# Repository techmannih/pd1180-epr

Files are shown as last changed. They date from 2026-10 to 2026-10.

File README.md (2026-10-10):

# PD1180-EPR — NEMA 34 Smart Motor-Mounted Stepper Controller with USB-C PD 3.1 EPR

PD1180-EPR is an 85.9 × 85.9 mm, four-layer controller for the ordered STEPPERONLINE 34HS31-6004S1 NEMA 34 motor (Amazon ASIN B091C83HWF). Its rated holding torque is 4.8 Nm and rated current is 6 A/phase; the driver RMS/hold-current setting and driven load remain unqualified. J1 is the dedicated 48 V / 5 A USB Power Delivery 3.1 EPR input; J10 is a separate USB 2.0 device-data port. The board combines protected power entry, a TMC5160A external-MOSFET motor stage, STM32G0B1 control, magnetic position feedback and industrial control interfaces.

**Revision:** r0.4 reference ECO · **Status:** CAD routing verified; powered validation pending · **Assembly:** top only · **Order status:** HOLD

**Reference-board changes:** Retain the separate PD POWER / USB DATA ports, industrial J7 harness and TMC5160 external bridges. Add TMP102 hardware temperature inhibit, INA240 phase-current diagnostics, ADS1115 bus telemetry and a DATA-powered logic supply. Place bootstrap/gate/bypass parts locally and preserve Kelvin connections to the shunt terminals. Native routing, DRC, schematic parity, ERC and Kelvin isolation pass. Physical USB power validation remains open. The STM32 commissioning firmware is motion-locked. TI programming and powered tests are also pending.

[View the board on tscircuit](https://tscircuit.com/techmannih/NEMA-34-Smart-Motor-Mounted-Stepper-Controller) · [Open the manufacturing release](release/) · [Read the reviewer checklist](docs/reviewer-checklist.md)

The main 3D tab shows the routed PCB with the ordered motor and proposed adapter. The image below shows the bare PCB. The release archives are regenerated for engineering review. Ordering remains on hold; the commissioning firmware keeps motion locked pending TI programming and powered validation.

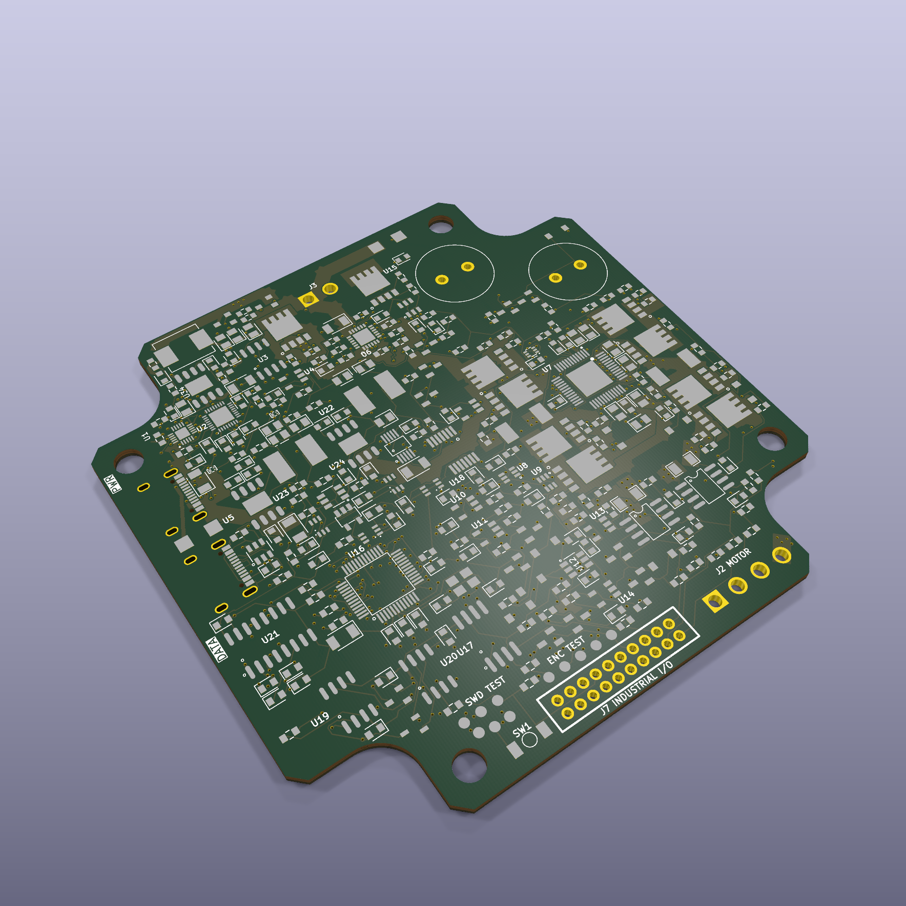
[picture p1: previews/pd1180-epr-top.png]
Routed r0.4 ECO PCB


## What must arrive with the assembled board

The intended purchase is **PCB fabrication plus complete assembly, programming and functional test**, so the delivered PCBA can operate with its specified motor, power source and harness. Bare-PCB electrical testing and soldering the components do not establish motor operation. Programming and powered testing must be explicitly included in the accepted assembly/test work order; they are not assumed to be included in an SMT assembly quote.

**The current release cannot yet deliver a ready-to-run motor controller.** No assembled hardware has been tested. U3's TI PD image is missing, and the supplied STM32 commissioning image deliberately blocks motor power and motion, including after `ARM`. The following deliverables are required before accepting a board as ready to run:

| Deliverable | Required handoff / present status |
|---|---|
| Complete populated PCBA | Matching Gerbers, BOM and CPL; 294 fitted parts on top, including an agreed through-hole/tall-part assembly plan. CAD verified; assembly not ordered. |
| U3 PD-controller EEPROM | Approved TI-generated TPS26750 full-flash binary, SHA-256 and programming/readback record. **Binary pending.** The requirements JSON is not flashable firmware. |
| U16 STM32 firmware | Board-specific, motor-enabled firmware with a recorded hash and validated motor/current settings. **Only motion-locked commissioning firmware is supplied today.** |
| Functional acceptance | Board serial number, firmware/configuration hashes and measured rail, PD, motor, fault and thermal results. **All powered results pending.** |
| External system | Confirmed motor, EPR source/cable, 24 V control source, mating harnesses, brake resistor/heatsink, magnet and mounting hardware; these are outside the populated-PCB BOM. |

First articles need staged engineering qualification using [the power-validation test matrix](docs/power-validation.md), followed by an agreed per-board acceptance test for the assembled batch. If the assembler does not provide programming or motor testing, arrange a separate commissioning provider before calling the delivery ready to run. The manufacturing request and pending programming fields are in [order-settings.json](release/order-settings.json); detailed acceptance requirements are in [assembly.md](docs/assembly.md).

The [provider request and first-article programming sequence](docs/assembly.md#request-to-send-to-the-assemblytest-provider) are ready for review. Provider acceptance and the [motor/load qualification inputs](docs/power-validation.md#qualification-work-sheet-for-the-provider) remain open. Programming and the accepted motor tests must finish before shipment.

## Connections and operation

The selected operating mode is **external STEP/DIR with USB setup and diagnostics**. The STM32 supervises power, configures the TMC5160A and checks faults. External pulses pass through the 24 V input circuitry to the TMC5160A, which drives the external MOSFET bridges and regulates the motor phase currents. USB DATA alone cannot power the motor. Industrial transceivers are fitted, but CANopen, serial motion commands and closed-loop positioning are not implemented in the current firmware.

Make motor/brake/harness connections with power removed and the bus discharged. Identify each motor winding from its verified pinout or a resistance measurement; wire colours are not a pinout.

| Connection | Wiring |
|---|---|
| J1 **PD POWER** | Source explicitly supporting a 48 V / 5 A EPR contract, with a suitable 5 A EPR cable. A USB-C connector alone does not establish this capability. |
| J10 **USB DATA** | USB data cable to the setup/diagnostics host. Its independent 5 V input supplies MCU logic, not VMOTOR. |
| J2 **MOTOR** | Pin 1 A1, pin 2 A2 (one winding); pin 3 B1, pin 4 B2 (the other winding). Never connect/disconnect the motor while powered. |
| J3 **BRAKE** | The selected resistor connects between pin 1 VMOTOR and pin 2 switched BRAKE_RETURN. Pin 2 is not a permanent ground. Fit the reviewed heatsink. |
| J7 **STEP/DIR** | Pin 6 STEP, pin 7 DIR, pin 18 hardware ENABLE; nominal 24 V inputs referenced to pin 8 GND. Use a compatible 24 V controller/level interface; do not treat these as direct 3.3 V GPIO inputs. |
| J7 **limits** | Pin 1 HOME, pin 2 STOP L, pin 3 STOP R. Qualify their polarity and stop response during commissioning. Full industrial pinout is below. |
| J7 pin 17 | Protected **VMOTOR, nominal 48 V**; not a 24 V control supply. Obtain the control-input 24 V supply separately. |

Use the physical pin-1 marker and numbered footprint, not the apparent left/right order of a photograph. The STEP/DIR transistor inputs invert their signals; validate step edge, direction setup/hold time and maximum pulse rate at the TMC5160A before configuring the external motion controller.

### First start with the supplied commissioning firmware

1. Complete the unpowered inspection in [bring-up.md](docs/bring-up.md). Keep J1 and the motor disconnected and hardware enable inactive for the initial J10 diagnostic check.
2. If U16 has not been programmed, use ST-LINK/SWD with SWDIO, SWCLK, NRST, GND and the board's 3.3 V reference. Program the verified `firmware.bin` from [the commissioning archive](release/pd1180-commissioning-firmware.zip) at `0x08000000`, verify and reset. Follow [firmware/README.md](firmware/README.md) for the exact MCU and power arrangement. This binary belongs in U16, not U3.
3. Connect J10 and open its USB CDC serial port. Send `HELP`, `STATUS`, `DRIVER` or `DISARM`, each followed by a newline. With J10 alone, `BOARD_OK=0` is expected because the PD-powered peripherals are off; `RUN=0` and `BRINGUP_REQUIRED=1` must remain set as shown.
4. `ARM` currently returns `BLOCKED: ECO hardware and TI configuration not verified`. This is expected, not a wiring workaround. Do not bypass the lock or bridge an enable signal to make the motor run.
5. Commission U3 and the J1 power path with the approved TI image and instrumented, staged tests before connecting a motor. Then qualify a motor-enabled STM32 release, initially below 1 A RMS and only increasing current after gate, current and thermal measurements pass. **This qualification has not happened yet.**

### Normal use after the motor-enabled release is qualified

Connect the confirmed motor, brake and industrial harness while unpowered, with STEP pulses stopped and hardware enable inactive. Connect J10 for diagnostics and J1 for motor power. Verify the approved PD contract, board/driver rails and fault status, select the qualified current/microstep settings, then explicitly arm and assert external enable. Apply a low-rate STEP train with DIR stable; increase speed and load only within the recorded operating envelope. Pulse frequency sets speed and DIR selects direction; the current setting is independent of pulse frequency.

To stop normally, decelerate the STEP train using the validated stop profile, remove enable and disarm before removing power. A fault, reset or power interruption must leave the bridge inhibited and require deliberate re-arming. Loss of torque is not a mechanical holding brake; a gravity-loaded axis needs its own holding arrangement. The final motor-enabled release must supply its exact command/settings procedure and measured operating limits; the commissioning image above cannot execute this normal-use sequence.

## Feature overview

| Area | Implementation |
|---|---|
| USB-C power | TPS26750 sink-only USB PD 3.1 EPR controller requesting 48 V / 5 A |
| USB ports | J1 PD POWER and J10 USB DATA; separate VBUS rails |
| USB protection | TPD4S480 on PD CC/SBU; USBLC6-4SC6 on DATA D+/D−/CC, independent 5.1 kΩ CC pulldowns and DATA VBUS sensing |
| Input protection | TPS26631 eFuse, inrush control, voltage qualification, current limit and reverse-current blocking |
| Motor stage | TMC5160A with eight 100 V CSD19534Q5A MOSFETs and two 33 mΩ phase shunts |
| Ordered motor | STEPPERONLINE 34HS31-6004S1, 4.8 Nm, 6 A/phase; approved driver current setting pending |
| Controller | STM32G0B1CBT6 with USB device, CAN, SPI, I²C and serial peripherals |
| Position feedback | Top-side AS5047P magnetic encoder at the shaft axis, with ABI test access |
| Temperature/current diagnostics | TMP102 hardware inhibit; two INA240 phase monitors; ADS1115 bus monitors |
| Motion inputs | 24 V Step/Dir plus HOME, left stop and right stop inputs |
| Communications | USB 2.0, CAN, RS485 and RS232 |
| Outputs | Hardware enable plus two protected low-side outputs |
| Braking | External switched brake-resistor interface with independent overvoltage shutdown |
| Programming | SWD for STM32 and configuration EEPROM for the PD controller |
| Assembly | 294 JLC-sourced fitted parts plus 11 service test pads, all on top |

The board powers up inhibited. A valid EPR contract, eFuse status, motor-power-good signal, voltage window, external hardware enable and MCU request must all agree before the bridge can run. Reset defaults keep `POWER_PERMIT`, `MCU_RUN`, `RS485_DE`, both protected outputs and standalone-mode selection inactive.

## Power architecture

```text
J1 PD POWER VBUS -> reverse blocking / eFuse -> VMOTOR -> bridge power / TMC5160 VS
        |                                       |       motor J2 / brake J3
        |                                       +-> U34 12 V -> TMC5160 VSA/12VOUT
        +-> U5 3.3 V startup supply              +-> U22 3.3 V brake-control backup
                         U23 / U24 reverse-blocked OR -> V3V3
J1 CC1/2 -> U1 protection -> U2 TPS26750 EPR controller
J10 USB DATA D+/D- -> D15 shunt ESD -> R71/R72 -> STM32 USB
J10 VBUS -> U28 current limiter -> U25 LDO -> V3V3_USB
board V3V3 / V3V3_USB -> U26 / U27 reverse-blocked OR -> V3V3_MCU
```

DATA alone powers MCU setup/diagnostics on V3V3_MCU. Industrial interfaces, flash, encoder and sensors remain on board V3V3 supplied by J1/VMOTOR. Open-drain chip selects and inactive peripheral pins prevent MCU-driven backfeed. Firmware now implements USB suspend with STOP0, watchdog wake and fresh power/sensor qualification after resume; measured current, inrush, wake timing and source handovers remain unverified. U22 retains VMOTOR-fed brake control. The commissioning image keeps the motor locked.

The requested contract is 240 W. The nominal eFuse current limit is approximately 4.48 A, so the board-side motor input limit is about 215 W at 48 V before conversion and switching losses. USB input current and phase current are different quantities; the motor-stage target is 5.5 A RMS per phase.

The 940 µF motor bulk bank stores only about 0.188 J between 48 V and the revised nominal 51.99 V brake turn-on threshold. It cannot absorb sustained regeneration. J3 connects a separately selected braking resistor and heatsink; 10 Ω / 300 W is an initial engineering target, not a validated load rating. Actual speed, attached inertia, stopping time and duty cycle determine the final resistor and thermal design. U34 now supplies the driver separately at nominal 12 V; see [the power ECO calculations and remaining tests](docs/power-validation.md).

Detailed calculations, tolerances and protection behavior are recorded in [docs/design.md](docs/design.md). The separate CC, USB-data and current-monitor paths are traced pin by pin in [docs/usb-pd-architecture.md](docs/usb-pd-architecture.md).

## Motor control and feedback

The TMC5160A controls two external MOSFET bridges. Four bootstrap capacitors, charge-pump support, gate resistors, local driver rails and two 3 W current shunts are represented explicitly. Native ramp control selects the board's limit inputs. External STEP/DIR is the selected product mode. The former encoder/mode-pin conflict is corrected in the ECO source; motion stays inhibited until native and powered validation pass.

The top-side AS5047P shares SPI with the motor driver and external flash, using an independent chip-select. Its ABI outputs are available on five top service pads for probing. The ordered motor is single-shaft, and its CAD does not identify an accessible rotating rear shaft or an approved magnet attachment. The previous QSH-specific holder and magnet stack have been withdrawn; encoder attachment, field, retention and working gap remain unresolved; see [motor assembly](docs/motor-assembly.md).

Firmware must configure current scaling, gate drive, dead time, chopper behavior, motion limits and encoder calibration for the actual motor. A register default is not approval for 5.5 A operation.

## Interfaces

| Connector | Function | Pins / notes |
|---|---|---|
| J1 | PD POWER | 48 V / 5 A requested EPR contract; CC/SBU protection; no data connection |
| J10 | USB DATA | USB 2.0 D+/D−, independent CC pulldowns, ESD and VBUS attach sense |
| J2 | Motor | A1, A2, B1, B2 |
| J3 | External brake | VMOTOR and switched resistor return |
| J7 | Industrial harness | 20-pin keyed JST PHD carrying all former J6/J7/J9 signals |

J7 pinout: 1 HOME, 2 STOP L, 3 STOP R, 4 IN0, 5 IN1, 6 STEP, 7 DIR, 8 GND, 9 RS232 TX, 10 RS232 RX, 11 GND, 12 CAN H, 13 CAN L, 14 GND, 15 RS485 A, 16 RS485 B, 17 **VMOTOR (48 V nominal)**, 18 hardware enable, 19 OUT0, 20 OUT1. Inputs remain 24 V nominal. This harness is not pin-compatible with the previous headers; pin17 is not a regulated 24 V output. Use the numbered physical pin map in `hardware-contract.json` when making the cable.

CAN and RS485 remain non-isolated. Termination and RS485 bias belong at the system level. SWD/reset/status and encoder ABI signals remain on labelled top-side service pads. There are five cable connectors, with all industrial features retained.

## Firmware contract

The generated STM32 pin contract lives in [docs/firmware-pinmap.json](docs/firmware-pinmap.json) and [firmware/include/board_pins.h](firmware/include/board_pins.h). The shared safety logic has host tests; the pinned PlatformIO target builds a flashable USB commissioning image with motor outputs locked pending the ECO validation. See [firmware build/programming instructions](firmware/README.md).

| Function | MCU signals |
|---|---|
| Motor SPI | `TMC_CS_N`, `SPI_SCK`, `SPI_MISO`, `SPI_MOSI`, `TMC_DIAG0`, `TMC_DIAG1` |
| Encoder/flash | `ENC_CS_N`, `FLASH_CS_N` on the shared SPI bus |
| USB | `USB_VBUS_SENSE`, `USB_DM`, `USB_DP` |
| Power safety | `BOARD_POWER_SENSE`, `EFUSE_FAULT_N`, `MOTOR_PG`, `VMOTOR_OK`, `POWER_PERMIT`, `MCU_RUN` |
| Motion inputs | `STEP_IN`, `DIR_IN`, `STOP_L`, `STOP_R`, `HOME_IN` |
| Communications | CAN RX/TX, RS485 RX/TX/DE and RS232 RX/TX |
| Monitoring | `PHASE_A_ADC` / `PHASE_B_ADC` on PA0/PA1; ADS1115 bus monitoring and TMP102 temperature on I²C |

The motor-qualified STM32 firmware and TI-generated TPS26750 full-flash image are release inputs. Reset circuitry is designed to inhibit the board with blank U3 and U16; that behavior still requires a powered test. Programming both devices is necessary but does not, by itself, establish motor readiness. The current STM32 image remains motion-locked even if U3 is programmed.

U16 remains STM32G0B1 because this board uses its native USB device, FDCAN, ADC, SPI, I²C, UART and SWD peripherals at the same time. RP2040 is not a drop-in substitute and has no native CAN controller; changing to it would add a CAN controller and require a new pin map, firmware target, placement and route. The exact fitted STM32 code `C2847904` is covered by the same live-stock gate as every other fitted part.

## Schematic organization

The design is split into sixteen functional sheets:

| Sheet | Scope |
|---|---|
| USB PD | Dedicated J1 power receptacle, CC/SBU protection, PD controller and EEPROM |
| USB DATA | J10 USB 2.0, CC pulldowns, ESD and VBUS attach sensing |
| Logic power | USB-side and motor-side buck supplies with reverse-blocked rail ORing |
| Motor power | eFuse, reverse blocking, bulk capacitance and motor-bus qualification |
| Driver power | U34 regulated 12 V supply for TMC5160 VSA/12VOUT and brake-gate drive |
| Motion | TMC5160A control, mode selection, limit inputs and encoder interface |
| Bridge A / Bridge B | External MOSFET half-bridges, bootstrap networks and phase shunts |
| Brake | Bus-voltage comparators, brake MOSFET drive and external resistor connector |
| MCU | STM32G0B1, clock, reset, SWD, flash and shared control buses |
| Encoder | Top-side AS5047P supply, SPI/ABI signals and service test pads |
| USB logic | DATA current limiter, 3.3 V LDO and reverse-blocking source selection |
| Telemetry | Temperature inhibit, phase-current amplifiers and bus-monitor ADC |
| Inputs | 24 V Step/Dir, stop, home and digital input conditioning |
| Outputs | Protected low-side outputs and hardware enable chain |
| Serial | CAN, RS485 and RS232 transceivers with ESD support |

The source and regenerated release contain sixteen schematic sheets.

## PCB, mechanics and assembly

| Property | r0.4 ECO value |
|---|---:|
| Board outline | 85.9 × 85.9 mm TMCM-1180 V1.1 stepped perimeter with four concave 5.9 mm arcs |
| Copper layers | 4 |
| Finished thickness | 1.6 mm |
| Copper weight | 1 oz on every layer |
| Mounting | Four 4.2 mm holes on the documented asymmetric motor pattern |
| Power corridor | Nominal 2.4 mm with 0.16 mm zone clearance |
| General/power via | 0.60 mm pad / 0.30 mm finished drill |
| MOSFET drain-pad thermal vias | 40 total: four 0.60/0.30 mm through vias under each of ten CSD19534Q5A drain pads; epoxy filled and copper capped |
| Dense signal via | 0.50 mm pad / 0.30 mm finished drill |
| Minimum via drill | 0.30 mm throughout the source, routed board and manufacturing exports; no smaller-drill exceptions |
| Assembly side | Top only |
| Solder mask / legend | Green / white |

All fitted components, including the centered encoder, its local bypass parts, logic power and labelled service pads, are on top. No bottom paste is required. The bottom carries the `ts` and `Made with tscircuit` board marking and remains available for copper routing. Bulk capacitors and through-hole headers may require selective or hand soldering. The encoder magnet gap and orientation require physical validation after this assembly-side change.

The completed KiCad route passes all-severity DRC, connectivity, schematic parity, ERC and terminal-only Kelvin checks. Nominal power-zone coverage is measured by routed length on the matching net/layer, independent of trace splitting. Clipped necks and temperature rise still need powered validation. The nominal 2.4 mm / 1 oz external-layer IPC-2221 estimate is 6.12 A at a 20 °C rise; it does not validate clipped pours or the thermal performance of a finished board.

The printable [mounting template](mounting-template.svg) is generated from `hardware-contract.json` plus the hash-locked TMCM-1180 V1.1 STEP extraction in `engineering/tmcm-1180-v11-mechanical-reference.json`. It includes the exact stepped perimeter, asymmetric holes and a 20 mm calibration bar. Print it at 100% to inspect the PCB pattern. **Direct rear mounting to the ordered 34HS31-6004S1 is not established.** Its documented mounting interface is the front flange; existing rear case screws are not approved accessory threads. [Motor assembly](docs/motor-assembly.md) describes a proposed front-supported adapter. A pattern match to the PD86 reference is not a direct-fit approval.

The exact ordered-motor CAD and proposed adapter appear in the default 3D view and remain selectable in `motor-assembly.circuit.tsx`, using `assembly.subassembly`. All parts remain on top. The adapter is not qualified for fabrication, and no encoder holder or magnet is modeled for this motor.

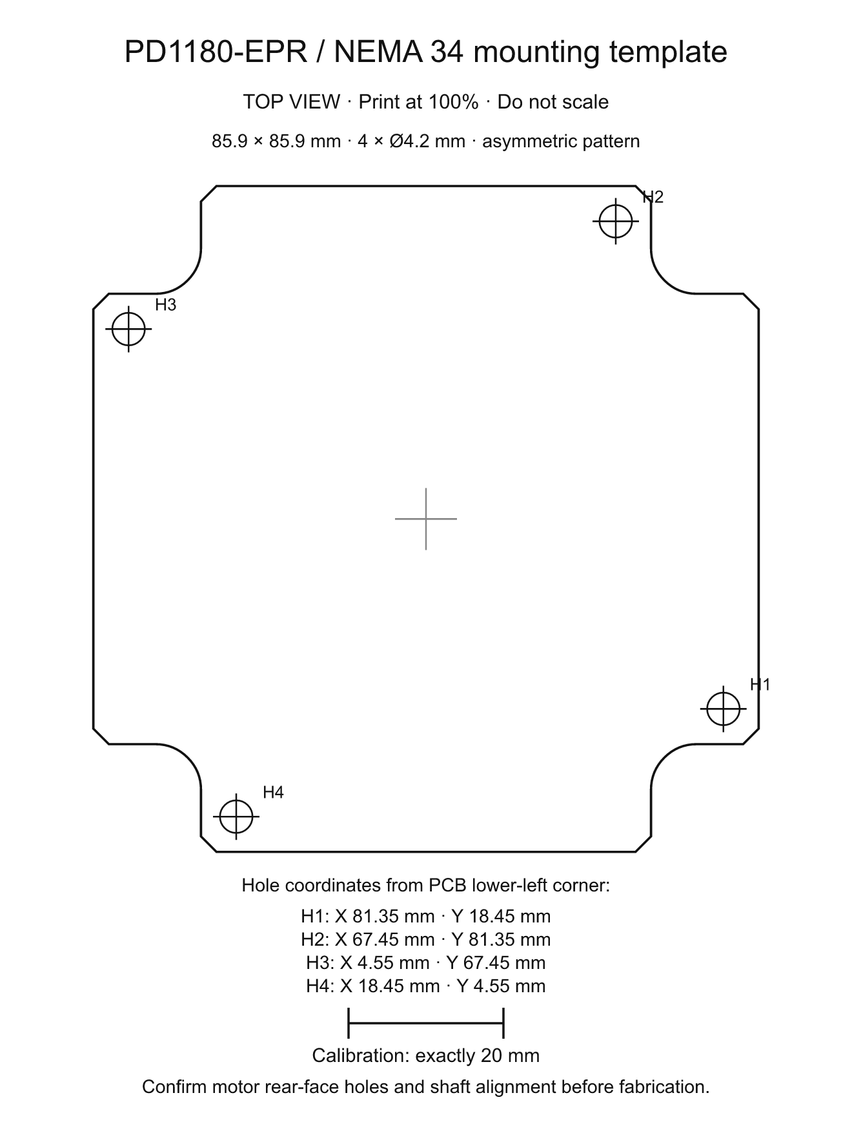
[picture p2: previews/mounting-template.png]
PD1180-EPR mounting template


## Parts and procurement

- 294 populated components use exact JLCPCB/LCSC identities.
- The fitted BOM contains 83 unique LCSC codes.
- The latest committed live check reports 83/83 available at its recorded timestamp; refresh stock for the actual order before purchase.
- Eleven selected alternative candidates are currently available.
- TPD4S480 has no approved drop-in replacement; a lower-voltage CC protector is not suitable for 48 V EPR.
- Automatic substitution is disabled. Package, pinout, polarity, voltage, current and thermal limits must be reviewed before any change.

The EPR source, certified 5 A EPR cable, 34HS31-6004S1 motor, shaft magnet, brake resistor/heatsink, mating housings, contacts, wire and external bus termination are system items outside the assembled PCB BOM. See [docs/procurement.md](docs/procurement.md) and [sourcing/](sourcing/).

## Verification

Run the same fail-closed review used in CI:

```sh
bun install --frozen-lockfile
bun run review
```

The review covers the pinned toolchain, compact tscircuit cloud package, TypeScript, firmware pin contract and host tests, source topology, netlist, the viewer-equivalent schematic style analysis, schematic/PCB placement, decoupling, exact supplier identities, top-side assembly, local critical copper, shorts, native KiCad PCB DRC and schematic ERC, power routing, route fingerprint, live stock, alternatives, preview export, release archives and recursive hashes.

Current verification evidence:

| Gate | Result |
|---|---|
| Native KiCad PCB DRC + schematic ERC | PASS — 0 PCB violations, unconnected nets, parity issues and ERC violations |
| Schematic style | PASS — 0 issues across all viewer analysis categories |
| Topology regression | PASS — 44 tests covering topology, motor-view preservation, via identity and power-copper geometry |
| Kelvin-check regressions | PASS — 11 native regressions and all 9 final-board paths |
| Decoupling | PASS — 46/46 native IC-to-capacitor paths |
| Assembly | PASS — 294 fitted parts plus 11 service test pads on top |
| Stock | PASS — 83/83 unique fitted LCSC codes available at the recorded timestamp |
| Alternatives | PASS — 11/11 selected candidates available |
| Release delivery | Current ECO review artifacts; ordering remains on hold |
| Route identity | Current source, local constraints and final PCB hash match |
| USB suspend power management | MCU-only rail and STOP0 path implemented; hardware current/timing unverified |

Machine-readable evidence is stored in [docs/verification.json](docs/verification.json), [docs/checks/schematic-style.json](docs/checks/schematic-style.json), [docs/feature-parity-check.json](docs/feature-parity-check.json), [docs/board-standards-check.json](docs/board-standards-check.json), [docs/power-routing-check.json](docs/power-routing-check.json), [docs/stock-report.json](docs/stock-report.json) and [delivery-manifest.json](delivery-manifest.json).

## Manufacturing release

The `release/` payload contains current ECO review files. **Do not order yet:** powered USB, current/thermal and system qualification remain open. Legacy archive filenames retain the r0.3 suffix for tool compatibility; their hardware contract and board markings identify r0.4. The package contains:

- PCB Gerber ZIP and the routed KiCad project ZIP;
- complete manufacturing ZIP with drills, Gerbers, DRC, BOM, CPL and project files;
- JLCPCB BOM and top-side placement CSV;
- ZIP-packaged 3D GLB plus top and bottom renders;
- sixteen schematic-sheet SVGs;
- order settings, hardware contract, schematic-style evidence, power-routing evidence and release status;
- delivery manifest and recursive SHA-256 hashes.

After a new verified release exists, apply its order settings: four layers, 1 oz copper on all layers, 1.6 mm thickness, filled/capped via-in-pad and top-side assembly. Review orientation, polarity, connector direction and the through-hole assembly plan before ordering.

The hosted tscircuit editor opens `release/circuit.json` by default: its 3D view includes the ordered motor and adapter proposal, and its PCB/schematic views retain the verified board. The authoritative editable source remains `index.circuit.tsx`. Its file selector includes all source TSX files, all imported components under `imports/`, and `release/circuit.json`. The cloud build compiles/transpiles `index.circuit.tsx`, then builds `release/circuit.json` into `dist/release/circuit.json` for the hosted viewer and static site. Imported components remain selectable without each becoming a separate CI board build. Run `bun run check:cloud-package --built` after the cloud build to verify the selected preview exists and exactly matches the routed artifact. Cloud autorouting stays disabled for the source preview.

After pulling updates, run `bun install --frozen-lockfile` and restart `bun run dev`. The dev command checks the installed toolchain before starting. `tscircuit.config.ts` makes interactive previews use the pinned local component definitions and disables preview autorouting, just like the build. This prevents remote pin-metadata requests from holding the main-board render open while another component is selected. Live supplier stock checks still run in `bun run review`.

Run `bun run build:pcb` (also `bun run build`) to refresh the default routed view from the current source. This checks the saved PCB fingerprint, native DRC report and local trace continuity, preserves the schematic exactly, and updates only viewer delivery hashes. Select `index.circuit.tsx` to edit the source and any `imports/` file to inspect that component. `release/circuit.json` is the final routed view. After regeneration it verifies that the compiled motor assembly preserves every code-defined board record, including the 16-sheet schematic, then replaces preview copper with the exact traces, vias and filled-zone polygons imported from the final KiCad board. `bun run check:cloud-viewer` regenerates that artifact in memory, checks every routed-port mapping and compares its copper counts with the KiCad import. The GitHub release importer materializes other supported tracked files before starting the CLI, so `bun run check:cloud-package` checks source/import visibility, the configured upload and the larger fixed-filter GitHub payload.

## Repository map

| Path | Purpose |
|---|---|
| `AGENTS.md` | Automatic design and review rules for AI-assisted changes |
| `board-markings.tsx` | Product identity and rear-side tscircuit attribution |
| `feature-parity.tsx` | Machine-checked product feature contract |
| `board-standards.json` | Machine-readable fabrication, via, marking, assembly and delivery policy |
| `hardware-contract.json` | Product dimensions, ratings, controller and reset-safe outputs |
| `mounting-template.svg` | Print-at-100% mechanical fit template generated from the hardware contract |
| `index.circuit.tsx` | Authoritative code-defined circuit, schematic layout and PCB intent |
| `release/circuit.json` | Generated hosted-viewer circuit with source schematic/3D data and verified KiCad copper |
| `engineering/` | Reviewer map linking contracts to generated evidence |
| `imports/` | Locally pinned component models and symbol/footprint corrections |
| `firmware/` | Safety state machine, generated pins and TMC5160A startup configuration |
| `routing/` | Power-copper requirements and guarded route fingerprint |
| `checks/` | Pinned viewer-equivalent review engine used by local and CI checks |
| `docs/` | Design calculations, assembly, procurement, bring-up and verification evidence |
| `scripts/` | Documented generation and fail-closed review tools |
| `sourcing/` | Stock-qualified BOM, alternatives and external-system items |
| `previews/` | Lightweight images used by this README and tscircuit package |
| `dist/` | Generated circuit, schematics, routed PCB and manufacturing outputs |
| `release/` | Engineering review handoff with archive/hash verification; ordering remains on hold |

## Bring-up and remaining gates

The r0.4 ECO files become a prototype fabrication handoff only after the order hold is cleared. Archive and KiCad basenames retain the legacy `r0.3` suffix for pipeline compatibility; the hardware contract, board silkscreen, release status and hashes identify the actual r0.4 ECO revision. They are not a production release. Before applying motor power:

1. Generate and independently review the sink-only TPS26750 EPR configuration, then program U3.
2. Qualify the integrated STM32 target on the bench, verify fault shutdown and produce the motor-enabled release with recorded configuration/hash evidence.
3. Qualify the ordered motor’s adapter and shared front-flange fastening; establish rotating-shaft access, encoder attachment, magnet field/gap and enclosure clearances.
4. Select the brake resistor/heatsink from measured load inertia, speed and stopping duty.
5. Perform current-limited rail bring-up before fitting the motor.
6. Measure gate waveforms, phase current, bus overshoot, connector temperature and PCB temperature.
7. Complete USB PD, cable-fault, regeneration, ESD, EMC and representative-load testing.

The staged procedure and sign-off points are in [docs/bring-up.md](docs/bring-up.md). Prototype-order gates and physical system-validation gates remain separate in [docs/release-status.json](docs/release-status.json).

Engineering review and ordering are separate gates: `bun run review` validates the current source, CAD, firmware, stock and delivery artifacts while retaining any documented order hold. `bun run check:release` additionally requires `fabrication_orderable: true`; it must fail until the order hold is cleared with evidence. A passing review/CI run is not authorization to order or a claim of powered hardware qualification.

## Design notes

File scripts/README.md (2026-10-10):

# Script catalog

Every executable script is listed here so a reviewer can understand the release pipeline without reverse-engineering the repository. `bun run check:script-catalog` fails when a script is added without documentation.

| Script | Purpose |
|---|---|
| `add-board-planes.py` | Adds board-outline-conformal GND and V3V3 planes to the routed four-layer PCB. |
| `build-firmware.mjs` | Builds and packages the pinned STM32 ARM commissioning image; --check proves source/artifact hashes match and motion remains locked. |
| `check-operating-mode.mjs` | Fails for encoder connections incompatible with the selected external STEP/DIR mode; records the exact hardware blocker. |
| `check-alternatives.mjs` | Rechecks reviewed LCSC alternative parts, their pinned live package names and intended package compatibility, then writes availability evidence. |
| `check-assembly.mjs` | Enforces exact supplier identities, stock evidence, encoder position and permitted top/bottom placement. |
| `check-board-standards.mjs` | Applies `board-standards.json` to geometry, vias, markings, sheets, DRC and assembly outputs. |
| `check-cloud-package.mjs` | Guards the source entrypoint, visibility of every TSX/import and both explicit CI build targets; `--built` verifies the selected hosted output exists and matches the complete routed JSON; enforces a compact upload, rejects oversized loose GitHub-import files and prevents runtime `@tsci/*` dependencies that are not locally pinned under `imports/`. |
| `check-cloud-viewer.mjs` | Regenerates the hosted viewer artifact in memory and proves it preserves the source schematic/3D model, verified KiCad copper counts and a named source net for every route, via and pour. |
| `cloud-viewer-net-names.test.mjs` | Regresses KiCad 10 named branch routes without pad endpoints, via/pour net remapping, unchanged schematic/route geometry and rejection of missing, unknown or conflicting net identities. |
| `check-feature-parity.mjs` | Verifies the product feature contract against compiled components, nets and evidence, enforces tscircuit's standard USB-C connector model, and checks permitted assembly layers. |
| `check-decoupling.mjs` | Measures placed/routed bypass connections against local distance and length limits. |
| `check-delivery.mjs` | Verifies required release files, root/release manifest identity, recursive SHA-256 hashes, archive readability and source/release consistency. |
| `check-firmware.mjs` | Builds and runs the host-side safety-state/TMC configuration tests. |
| `check-import-previews.mjs` | Executes every imported TSX as a standalone viewer entrypoint and requires both PCB and schematic component output without component-creation failures. |
| `check-kicad-drc.mjs` | Fails on any final KiCad PCB DRC violation, unconnected item, schematic-parity issue or nested schematic ERC violation. |
| `check-local-copper.mjs` | Checks manually constrained local copper and critical short routing. |
| `critical_copper.py` | Reads Kelvin/analog-return paths from compiled source. `keepouts` reserves their top-layer pours, `dsn --dsn INPUT` protects them from new router branches and replaces completed branch destinations/copper with obstacles in the disposable DSN. Optional `--fixed-board SEED` fixes source copper while allowing the remaining incomplete route to move. `check` proves final native copper remains intact and joins other same-net copper only at the designated receiving terminal. Inputs: critical-path policy, source circuit JSON and native PCB; output: PCB, DSN or hash-bound report. |
| `check-critical-copper.mjs` | Requires passing native Kelvin evidence for every policy path and exact hashes of the final PCB, compiled source, policy and native checker; rejects stale or incomplete reports. |
| `check-native-decoupling.py` | Measures each required IC-to-capacitor connection using final native top-layer tracks and pads; writes hash-bound evidence and rejects missing paths or paths longer than 5 mm. Arguments: board path and output JSON. `check:decoupling --native` validates this evidence during routed review. |
| `circuit-source-hash.mjs` | Hashes every circuit element and metadata field except the CLI filesystem cache key, canonicalizing derived trace lengths to 1e-12 mm across platforms, so regenerated reports cannot invalidate unchanged native circuit evidence. Shared by the native checker and its evidence verifier. |
| `test-critical-copper.py` | Native KiCad regressions: accept a load connection at the shunt terminal; reject missing sense copper, a same-net spur, a connection at the far edge of the IC land, or a plane via before that terminal; check that DSN reservations leave other destinations intact. |
| `check-netlist.mjs` | Validates source connectivity and required nets. |
| `power-audit.mjs` | Reads compiled connectivity, fitted values and firmware to screen operating limits, supply isolation, forbidden IMON bypass capacitors, protection tolerances and power losses; writes hash-bound calculations while retaining hardware qualification holds. |
| `power-audit.test.mjs` | Rejects merged/missing supply nets, non-numeric inductance and IMON bypass capacitors including renamed references/net aliases; regresses operating-limit and tolerance calculations. |
| `check-power-routing.mjs` | Audits final KiCad power corridors, clearances, layers, via counts and analytical current screen. |
| `release-gates.test.mjs` | Proves held designs remain reviewable but not orderable, and both modes reject failed or stale evidence. |
| `check-release.mjs` | Checks engineering evidence and unchanged inputs; default mode enforces the order hold. `--review` permits a verified review package with explicit hold reasons while never permitting failed CAD checks. |
| `check-schematic-style.mjs` | Runs the same placement/style analyzer used by the tscircuit schematic viewer, records per-sheet evidence and fails unless the issue count is zero. |
| `check-routing-fingerprint.mjs` | Guards saved routing against unreviewed topology, footprint, placement, source copper, routing-policy or seed-generator changes. |
| `check-script-catalog.mjs` | Ensures this catalog mentions every `.mjs` and `.py` script. |
| `check-stock.mjs` | Refreshes exact JLCSearch code, package and stock evidence for the fitted BOM; missing package expectations fail closed. |
| `check-source-schematic.mjs` | Audits all fixed-size schematic sheets, functional annotations, source-net fanout, the separate USB-C PD POWER and DATA paths, capacitor and test-point connectivity, and the exact intentional no-connect set. |
| `check-toolchain.mjs` | Verifies the pinned Bun runtime, exact dependency versions and installed tscircuit toolchain. |
| `clean-silkscreen.py` | Removes dense passive references and applies reviewed markings. Optional `--clip-passive-outlines` trims R/C outline fragments away from solder lands and adjacent markings while retaining references and polarity marks; native DRC remains mandatory. |
| `design.test.mjs` | Regression tests electrical topology, fixed parts and safety behavior. |
| `export-assembly.mjs` | Generates JLC-compatible BOM/CPL and the assembly review data. |
| `export-routing-interchange.py` | Exports a routing-only copy with unique, world-aligned footprint images while asserting every pad coordinate, layer, angle and net is unchanged; no blanket bottom rotation is needed. |
| `export-kicad-route.mjs` | Exports the current Circuit JSON to a fresh KiCad PCB/project and hierarchical schematics for external routing. |
| `export-manufacturing.mjs` | Uses KiCad CLI to export Gerbers, drills, positions, PCB DRC, schematic ERC, top/bottom renders and the manufacturing ZIP. |
| `export-previews.mjs` | Renders top PCB and all functional schematic sheets. |
| `export-release.mjs` | Regenerates final routed-board and exact-motor assembly GLBs, checks their geometry/axis alignment, requires fresh valid outputs, then builds the release, synchronized delivery manifests, sourcing tables and hashes. |
| `export-silkscreen-evidence.py` | Records every visible final KiCad top/bottom silkscreen label and its physical text size. |
| `generate-firmware-pins.mjs` | Generates the STM32 pin header from the hardware pin contract or checks it for drift. |
| `generate-cloud-viewer.mjs` | Verifies that the motor assembly preserves every source board record, then combines its board/motor CAD with routed KiCad traces, vias and pours for deterministic hosted PCB viewing. Omits only the CLI's filesystem cache key, which includes generated release/report files; source and copper provenance remain enforced by SHA-256 inputs, routing fingerprint and delivery hashes. |
| `generate-motor-assembly.mjs` | Converts the hash-locked ordered-motor STEP and parametric adapter proposal into GLBs and immutable, SHA-256-checked public runtime CAD URLs. Reads engineering/mechanical/assembly.json; custom hardware remains unqualified. |
| `check-motor-assembly.mjs` | Screens final routed component meshes against all four screw-head envelopes and exact motor meshes against the proposed support posts; verifies the axial stack, unresolved encoder status, CAD height axis and exported assembly orientation. Accepts board GLB and optional assembly GLB paths. Writes docs/motor-assembly-check.json; does not certify physical/magnetic fit. |
| `generate-mounting-template.mjs` | Generates the 100%-scale SVG/PNG mounting template from the hardware contract and hash-locked STEP perimeter evidence, then detects stale copies. |
| `generate-routing-report.py` | Generates route counts and completion state from the final KiCad board, DRC JSON and manufacturing report. |
| `import-routing-copper.py` | Imports SES copper from the normalized routing copy, rejects placement changes, and preserves the original board footprints; `--restore-critical-branches` restores source Kelvin branches reserved as DSN obstacles and rejects premature joins before saving. Native DRC remains mandatory. |
| `import-routed-kicad.mjs` | Imports externally routed KiCad copper into reviewable Circuit JSON artifacts. |
| `import-specctra-route.py` | Imports a Freerouting Specctra SES result into its matching KiCad PCB, reverses the temporary bottom-placement routing compensation, and records connectivity counts. |
| `make-power-only-dsn.py` | Produces a power-focused Specctra routing input for controlled routing work. |
| `normalize-kicad-parity.mjs` | Reconciles a routed KiCad board with a fresh source export, fails closed on reference, footprint, net and pin drift, and publishes output only after all-severity PCB DRC, schematic parity and native schematic ERC pass. |
| `normalize-generated-svgs.mjs` | Removes generator-only trailing whitespace so previews remain deterministic in review. |
| `prepare-plane-escapes.py` | Adds short 0.20 mm ground/board-supply escapes to 0.60/0.30 mm vias before internal-plane routing. Preserves Kelvin isolation and leaves inaccessible pads in the router netlist; native DRC and filled-plane connectivity remain mandatory. |
| `test-plane-escapes.py` | Native connectivity regression: existing capacitor-return vias and plated connector pads must not receive redundant plane fanouts; isolated SMD lands still need an escape. |
| `prepare-routing-seed.py` | Adds the exact 40 drain-pad thermal vias, capacitor ground returns, and the pad-relative driver/supply escapes and common MOSFET pin links from `routing/pin-escapes.json` to a fresh export. Rejects altered pin identities and Kelvin shortcuts; native DRC and plane connectivity remain mandatory. |
| `prepare-routing-rules.py` | Applies 0.15 mm signal / 0.50 mm power escape rules and power via selection to the world-aligned routing export, without changing placement. Final power paths require corridor reinforcement and native DRC. |
| `power-copper-geometry.mjs` | Measures routed length inside same-net/same-layer nominal corridor outlines without depending on trace segmentation; identifies ties within actual MOSFET drain-pad locations. Does not certify clipped-fill ampacity. |
| `power-copper-geometry.test.mjs` | Regressions for split traces, overlapping or unrelated pours and false thermal-tie classification. |
| `prepare-r03-dsn.py` | Applies r0.3 routing classes and compensates the KiCad/Specctra bottom-footprint rotation convention before autorouting. |
| `reinforce-power-copper.py` | Adds clearance-aware power corridors and parallel transfer vias to the final KiCad route. |
| `refresh-routed-preview.mjs` | Builds the latest source, checks local route continuity and the saved PCB fingerprint/DRC, refreshes the routed viewer without changing schematic records, and updates only its delivery hashes. Does not approve a new manufacturing release. |
| `remove-isolated-zones.py` | Removes generated copper islands that do not connect to the intended net. |
| `sync-generated-docs.mjs` | Synchronizes generated manifest and pin/placement documentation. |
| `verify.mjs` | Runs independent checks, preserves logs and writes root Markdown plus machine-readable verification summaries. |
| `via-net-identity.test.mjs` | Verifies the exact final KiCad drain-pad thermal-via count, dimensions, layers and net identity for every CSD19534Q5A, and enforces the user-required 0.30 mm minimum via drill in the native board, compiled source and KiCad rules. |

The Python routing helpers are board-specific. Do not reuse their geometry on another board. The check patterns, failure behavior and documentation structure are reusable.

### Filled-copper investigation

- `export-filled-power-copper.py`: accepts `<board> <output.json>`. native KiCad/wx export of actual filled polygons, pads, tracks and plated transitions for critical power nets. Preserve the board SHA-256 in the output. Use KiCad's Python runtime after filling and passing DRC.
- `screen-filled-power-copper.py`: accepts `<copper.json> <NET> <grid_mm> <REF:pins> <REF:pins>`. offline DC sheet-conductance estimate, printed as JSON. Requires NumPy 2.0.2, SciPy 1.13.1 and Shapely 2.0.7 in an isolated environment. Run at two mesh sizes; native DRC remains authoritative for connectivity. The 35 µm copper, 20 µm barrel plating and evenly spaced four-layer model are assumptions. This is an exploratory resistance comparison, not a thermal/current-rating or order gate.

- `test-filled-power-copper.py`: analytic rectangular-sheet convergence and single-barrel identity checks for the optional offline screen. Run with the same isolated scientific Python environment.

- `check-usb-reference.py`: native filled-copper check of all four USB bottom-layer trunks, excluding only 0.45 mm signal-via antipads; requires local ground stitching within 2 mm. Arguments: board path and output report. Writes hash-bound geometric evidence, not USB electrical-compliance certification.
- `check-usb-reference.mjs`: rejects missing, failed or stale native USB reference-plane evidence during portable CI/review.

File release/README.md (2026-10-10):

# PD1180-EPR — NEMA 34 Smart Motor-Mounted Stepper Controller with USB-C PD 3.1 EPR

## r0.4 ECO review handoff — powered validation pending

**ORDER HOLD.** These are engineering review files. Powered USB, current/thermal and system qualification remain open; do not submit a fabrication order from this package.

The ECO separates PD POWER and USB DATA, consolidates the industrial harness and corrects the TMC5160 STEP/DIR pins while retaining external MOSFET bridges. USB DATA alone powers setup/diagnostics through a current-limited, reverse-blocked supply; the motor-bus backup supply is retained for brake control after PD loss. Status: power-eco-cad-verified-order-held. See `engineering/reviewer-eco.json` and `docs/step-dir-hardware-review.md`.

The ordered motor is STEPPERONLINE 34HS31-6004S1 (Amazon B091C83HWF). Its exact manufacturer STEP replaces the QSH reference. Rear case fasteners are not approved accessory threads; a front-flange adapter is proposed and encoder attachment remains unresolved. See `motor-assembly.md` for the proposed mount and ordered-motor limitations, nominal screw clearances and unresolved mechanical gates.

The included `pd1180-commissioning-firmware.zip` contains a real STM32 image with USB diagnostics. Motor power and motion remain locked. It does not prove motor operation.

The requested delivery is a fully assembled, programmed and functionally tested PCBA. `order-settings.json` requests programming and functional testing, with provider acceptance still pending. U3's TI full-flash image and a qualified motor-enabled U16 image are missing; the commissioning ZIP is not a substitute. Follow the repository README for wiring and diagnostic startup, and the included `assembly.md` for the provider request, first-article programming sequence and per-board acceptance requirements. Programming verification and the approved powered motor tests must pass before shipment. Blank or motion-locked boards do not satisfy ready-to-run delivery. No order or test service has been booked.

For the checked prototype handoff, use the newly generated Gerbers together with `jlc-bom.csv` plus `jlc-cpl.csv` for top-side assembly. Apply every value in `order-settings.json`, especially four layers, 1 oz copper on all layers, epoxy-filled/copper-capped processing for every via-in-pad listed in the order settings (including 40 MOSFET drain-pad and four U34 thermal vias), and top-side assembly.

Legacy archive/KiCad basenames retain the r0.3 suffix for pipeline compatibility; their contents, silkscreen and hardware contract are the r0.4 ECO identified by this delivery manifest.

The committed native KiCad checks have zero PCB DRC violations, zero unconnected items, zero schematic-parity issues and zero schematic ERC violations. See `kicad-drc.json` and `kicad-erc.json`. Live JLCSearch evidence covers all 83 unique populated LCSC codes. Reset circuitry is designed to inhibit motor power with blank U3/U16; this has not been measured on hardware. 48 V EPR requires a TI-generated TPS26750 full-flash image, and motor operation requires programmed STM32 firmware plus staged powered validation.

The tscircuit viewer-equivalent schematic style result is recorded across all 16 sheets; see `schematic-style-check.json`. `circuit.json` preserves that source schematic/3D model and replays the exact verified KiCad traces, vias and copper pours in the hosted PCB viewer without rerunning the cloud autorouter.

Power calculations and the unperformed bench-test matrix are in `power-validation.md`; `power-audit.json` and `native-decoupling-check.json` contain the numerical evidence.

Use `pcb-3d.png` and `pcb-bottom.png` for visual review. Print `mounting-template.svg` at 100% and measure its calibration bar before comparing it with the motor. The complete 3D model is stored as `pd1180-epr-r0.3-glb.zip` so cloud imports do not serialize a large loose binary. `delivery-manifest.json` records the exact file sizes and hashes, while `sha256.json` recursively covers this release directory.

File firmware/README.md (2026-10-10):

# PD1180 STM32 firmware

## Current deliverable: commissioning diagnostics, motion locked

`release/pd1180-commissioning-firmware.zip` contains an actual Cortex-M0+ ELF and raw binary for **STM32G0B1CBT6, LQFP48 GP, 128 KiB flash**. It is not a host executable. Do not use the different `...TxN` MCU variant. The archive manifest records source and image hashes.

The source ECO corrects the STEP/DIR conflict on U7 pins 23–25; the rebuilt hardware still needs verification. See `docs/step-dir-hardware-review.md`. This image deliberately keeps POWER_PERMIT, MCU_RUN and SD_MODE low, even if an ARM command is sent. It does not spin a motor. The TI TPS26750 EEPROM configuration is also not yet generated/programmed.

Implemented target functions: ST USB CDC, PB6/PB7 I2C1 status reads from TPS26750 address 0x20 with count-byte validation, TMP102 threshold programming/readback, ADS1115 bus readings, nominal ADC readings of DATA VBUS and both phase currents, safe GPIO initialization, and a 250 ms independent watchdog. USB attach/detach follows the PB0 VBUS divider. ADC values assume 3.3 V VDDA and require calibration. Hardware enumeration and timing remain untested.

USB commands are newline-terminated: `HELP`, `STATUS`, `DRIVER`, `DISARM`, `ARM`. ARM returns the blocking reason. Oversized lines are discarded. No command bypasses the hardware interlock. No CANopen, TMCL, RS485/RS232 motion or closed-loop encoder operation is claimed.

## Rebuild

Install Python 3 and `platformio==6.1.19` in a virtual environment. The pinned platform/core/compiler packages are fetched from the PlatformIO registry into `.cache/platformio`.

```sh
bun run check:firmware-pins
bun run check:firmware
PIO=/path/to/venv/bin/pio bun run build:firmware
bun run check:firmware-target
```

Build uses ststm32 20.0.0, ST Arduino core 3.0.0 (package 4.30000.0), and ARM GCC 12.3.1. The ST generic variant supplies the Cortex-M0+ startup, HAL, HSI PLL at 64 MHz and HSI48 USB clock. The external 16 MHz HSE is not required by this initial image. USB uses ST's generic CDC identity for prototype bring-up; assign an authorized product VID/PID before distribution.

## Program and inspect after assembly

Use ST-LINK SWDIO, SWCLK, NRST, ground and 3.3 V reference; avoid two competing board supplies. In STM32CubeProgrammer select the exact MCU, program `firmware.bin` at **0x08000000**, verify flash, then reset. Do not modify option bytes or mass-erase other devices. U3 requires a separate TI-generated image; do not flash this STM32 binary into the EEPROM.

First checks: POWER_PERMIT=0, MCU_RUN=0, SD_MODE=0, USB at default 5 V enumerates, STATUS reports the measured bus approximately correctly, no motor energization. Compare ADC readings to a meter. Record watchdog/reset and cable detach behavior. This is an untested prototype image, not proof of motor operation.

## Shared logic and tests

The pure-C safety state machine requires an explicit arm request, verified configuration/wiring, fresh data, an exact fixed 48 V/5 A contract, power-good/window/driver readiness and no protection/stop fault. Faults latch; DISARM then a new ARM is required. The commissioning target intentionally cannot satisfy the configuration/wiring gates before hardware bring-up.

Host tests cover no automatic arm, fifteen independent shutdown cases plus temperature and telemetry conversion boundaries, recovery latching, stalled timing, rejected non-48 V and under-current contracts, PD power role, capability mismatch, and physical GPIO mapping. Manufacturer pin order is independently checked: U16 pins 42–48 are PB3–PB9. The host harness also executes the actual target main loop with simulated USB/ADC/I²C for USB-only startup, rail qualification/loss/recovery, suspend/resume, detach and the ARM lock. It does not emulate STM32 STOP timing or measure current. Passing software tests does not substitute for physical bring-up.

## Reference-board diagnostics ECO

TMP102 at 0x48 uses active-low comparator mode, a two-conversion fault queue and 8 Hz conversion rate. Firmware writes and reads back the 70 °C trip and 55 °C release limits. An absent, reset, invalid or stale sensor blocks the safety state machine. U33 also gates RUN_SAFE from the physical ALERT line; manual rearm remains necessary after a software fault. The pure-C policy requests current reduction from 60–70 °C; motor current writes remain disabled in this commissioning image. PCB temperature does not establish MOSFET junction temperature.

ADS1115 at 0x49 samples VMON_ADC and IIN_MON in alternating, nonblocking single-shot conversions at 128 SPS and ±4.096 V range. PA0/PA1 instead measure the INA240A1 phase outputs (5 mΩ × 20 V/V = 100 mV/A). STATUS includes validity flags and nominal instantaneous mA. Values are not calibrated, PWM-synchronous or RMS measurements. Open-sensor, zero-offset, PWM transient and bandwidth checks remain mandatory.

DATA USB supplies only `V3V3_MCU` through the limiter, LDO and reverse-blocking OR. The board `V3V3` rail powers industrial interfaces, flash, encoder and sensors from PD/VMOTOR only. PB1 now measures that rail through R119/R120; the unused PD interrupt is replaced by this sense input while PD status remains polled. Peripheral access starts only after a 2.9–3.6 V reading remains healthy for 20 ms and stops on the first unhealthy sample. Chip selects are open-drain, released into external board-domain pullups. I²C and board-input pins become high impedance/analog when that domain is unavailable. USB-only STATUS reports `BOARD_OK=0` and invalid telemetry, rather than stale measurements.

USB suspend disarms, clears pending commands/telemetry, ends I²C and holds STATUS_GPIO low. STOP0 retains GPIO safety levels and the USB pullup. The RTC wake timer uses the same LSI oscillator as the IWDG and wakes the main loop every nominal 50 ms; only main reloads the 250 ms watchdog. USB EXTI wakes on resume/reset. Interrupts are briefly masked around the final suspend check and WFI, then the pinned HSI PLL and HSI48 clocks are restored before a pending USB handler can run. Clock restart failures reset the MCU. No option-byte watchdog freeze, auto-arm or USB remote wake is used. Resume requires fresh board-power qualification and sensor initialization; suspended time cannot make old samples valid.

The CDC descriptor declares bus power and requests a 500 mA configuration. Firmware and the MCU-only rail now implement suspend handling, but the 2.5 mA USB suspend ceiling, wake latency, pre-enumeration current, inrush, reverse current and source handovers still need instrumented hardware qualification. The TPS2553 is overload protection, not proof of USB compliance. No USB power state enables the motor.

Power-mode implementation references: [ST RM0444](https://www.st.com/resource/en/reference_manual/rm0444-stm32g0x1-advanced-armbased-32bit-mcus-stmicroelectronics.pdf), the pinned ST G0 HAL PCD/PWR/RTC drivers and [USB-IF suspend-current ECN](https://compliance.usb.org/index.asp?UpdateFile=Electrical).

## TMC5160 external STEP/DIR service

The SPI transport implements the TMC5160A two-datagram read pipeline at 1 MHz, mode 3, validates the write echo, and checks IOIN version/mode pins, GSTAT and DRV_STATUS. `DRIVER` reports these registers without configuring or clearing faults in the locked image. SPI becomes high impedance whenever VMOTOR or the board domain is unavailable.

The separately tested motor service initializes with DRV_ENN high and TOFF zero, verifies SD_MODE and disabled dcStep pins, programs the current and 16-microstep setting, then lets the safety state machine qualify driver readiness before MCU_RUN. The first tuning setting is IRUN=4, GLOBALSCALER=198 and 33 mΩ sense resistance: approximately 0.86 A RMS. Thermal reduction scales this requested current and rounds downward. Reset, transport failure or driver fault invalidates configuration; automatic reinitialization while armed is prohibited. DISARM is required before another attempt.

These paths are integrated but not enabled in the archived commissioning image. Enabling them requires recorded PD-image/readback and powered hardware qualification; no USB command can bypass that decision. Gate timing, switching overshoot, short-circuit detection and chopper parameters remain starting values requiring oscilloscope and current-probe checks before increasing toward 5.5 A RMS. No OTP is programmed.

Initialization explicitly writes SHORT_CONF=0x00010C06 (S2G=12, S2VS=6, 1 µs filter, normal delay) and DRV_CONF=0x00000400 (four-clock break-before-make, weak drive). ADI §11.2 recommends S2G≥12 when VS can exceed 52 V. These initial settings no longer depend on OTP variants; both writes require a valid SPI echo while TOFF remains zero. The timing is not a measured or qualified gate waveform. Regression tests cover both documented OTP variants and reject corrupted writes to either register.

Protocol and register reference: [ADI TMC5160A datasheet, rev. 1.18](https://www.analog.com/media/en/technical-documentation/data-sheets/tmc5160a_datasheet_rev1.18.pdf), sections 4 and 6. Host regressions cover pipelined reads, write corruption, invalid device responses, mode-pin mismatches, driver resets/faults, current derating and explicit rearm.

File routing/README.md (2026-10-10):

# PD1180-EPR — NEMA 34 Smart Motor-Mounted Stepper Controller with USB-C PD 3.1 EPR

## Routing release

The final KiCad board is generated from the verified connectivity route and reinforced by `scripts/reinforce-power-copper.py`. Dense package exits retain short neck-down traces; each critical routed segment receives a nominal 2.4 mm clearance-aware copper corridor, and layer transitions receive parallel 0.6/0.3 mm vias where geometry permits.

Isolated corridor polygons and slivers are removed after native fill/DRC. The original routed trace remains at each omitted location; current per-net coverage is recorded by `bun run check:power-routing` in `docs/power-routing-check.json`.

`bun run check:power-routing` checks corridor coverage, zone clearance, layer changes, via counts and the 1 oz IPC-2221 screening estimate. KiCad DRC remains the final geometric check.

## Filled-copper and USB follow-up

The MOTOR_A1 path from Q7 to R115 has a parallel B.Cu corridor tied through four existing drain-pad thermal vias and four new 0.60/0.30 mm transfer vias beside R115. Its F.Cu landing is 2.4 mm wide before clearance clipping. Terminal-only Kelvin checks remain mandatory. Filled-copper resistance screening and its assumptions are recorded in `engineering/filled-copper-review.json`; these estimates do not qualify temperature rise.

R71 now sits beside R72 on the top side. USB trunks use B.Cu over a local In2 GND region, with standard 0.50/0.30 mm return-stitching vias at the transitions. Five low-speed signals formerly crossing that region use other layers. `check-usb-reference.py` samples the actual filled reference plane every 0.05 mm along the four bottom trunks, excluding only signal-via antipads, and records nearby return vias. The portable checker binds this native report to the final PCB and checker hashes. The old route fails this check. The short top fanouts, final stack-up/impedance and USB electrical compliance still require review/measurement; a geometric pass does not replace an eye diagram.

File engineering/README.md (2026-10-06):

# Engineering evidence map

The repository keeps generated checks separate from design intent. This index maps the short root-level files to their complete evidence so reviewers and future board agents can find the authoritative record quickly.

| Engineering area | Contract / source | Generated evidence |
|---|---|---|
| Product features | `feature-parity.tsx`, `hardware-contract.json` | `docs/feature-parity-check.json` |
| Board markings | `board-markings.tsx`, `board-standards.json` | `docs/board-standards-check.json` |
| Mechanical pattern | `hardware-contract.json`, `mounting-template.svg` | `previews/mounting-template.png` |
| Power copper | `routing/requirements.json`, `scripts/reinforce-power-copper.py` | `docs/power-routing-check.json` |
| Assembly | `board-standards.json` | `docs/assembly-check.json`, `release/jlc-bom.csv`, `release/jlc-cpl.csv` |
| Component supply | `index.circuit.tsx`, `sourcing/` | `docs/stock-report.json`, `docs/alternatives.json` |
| Firmware interface | `hardware-contract.json` | `docs/firmware-pinmap.json`, `firmware/include/board_pins.h` |
| Complete review | `scripts/verify.mjs` | `verification.md`, `docs/verification.json`, `docs/checks/` |
| Delivery integrity | `board-standards.json` | `delivery-manifest.json`, `release/sha256.json` |

Compatibility patch files are added only when the pinned tscircuit version requires them. Do not carry version-specific prototype patches into this board without a failing regression fixture.

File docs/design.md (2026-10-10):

# PD1180-EPR — NEMA 34 Smart Motor-Mounted Stepper Controller with USB-C PD 3.1 EPR

## Electrical design and validation

### Scope

PD1180-EPR — NEMA 34 Smart Motor-Mounted Stepper Controller with USB-C PD 3.1 EPR is a 48 V EPR single-axis controller for a 5.5 A RMS stepper motor, with magnetic encoder feedback and serial/control interfaces. Its 85.9 mm square outline, four M4 mounting holes, shaft-axis location and connector placement are explicit in the PCB model. The selected 25 mm bulk capacitors require matching enclosure clearance.

### Power sequence

1. J1 VBUS initially supplies 5 V. U5, LMR36510, starts from this and provides V3V3_PD before any motor power is enabled. U23 passes that rail to board V3V3; U26/U27 combine it with DATA-derived V3V3_USB into V3V3_MCU. DATA USB powers the MCU only; industrial interfaces, flash, encoder and telemetry sensors require board V3V3. LM5164 was rejected for this position because its 6 V minimum input cannot bootstrap from default USB 5 V. J10 carries USB 2.0 D+/D− and independently powers setup/diagnostics through U28/U25.
2. U1, TPD4S480, protects J1's CC and SBU contacts. J1 data pins and the protected SBU outputs are unused. C2 is the required 1 µF local VPWR/LDO_3V3 bypass. U1's VBUS divider feeds U2's low-voltage VBUS sense pins. Q1 bypasses that divider in SPR with its source toward VBUS_LV and drain toward raw VBUS.
3. U2, TPS26750, boots in SafeMode: ADCIN1 to LDO_3V3, ADCIN2 to ground, I2Ct address 0x20. The 64 KiB EEPROM is at 0x50 on the independent I2Cc bus. An appropriate TI configuration image is required; a blank EEPROM does not negotiate 48 V.
4. PD POWER_PATH_EN is not a logic-level output. Q2/Q3 are the CSD17484F4 dual-NMOS non-inverting buffer used by the TPS26750 EVM: R9 and R12 are 0 Ω gate links, while R11 and R13 are 100 kΩ pull-ups to U2's own PD_3V3/LDO_3V3 rail. U4 then combines PD_PATH_OK with the MCU power permit. Firmware may assert that permit only after an active 48 V / 5 A EPR contract and valid fault status. Loss of the contract must remove the permit immediately.
5. U6, TPS26631, provides inrush/current limiting and voltage qualification. Q4 implements reverse-current blocking, with Q5 providing its fast gate pull-down. Motor bulk capacitance is downstream of this switch.
6. U22 generates V3V3_MOTOR from the switched motor bus. U23/U24 implement TI LM66100 Figure 17 continuous-output ORing: U23 CE senses V3V3_MOTOR, U23 ST drives U24 CE through LOGIC_OR_PRIORITY, and R111 pulls that interlock up to V3V3_PD. This removes the equal-input both-off condition of the simpler cross-coupled circuit. U24 ST is grounded because its status indication is unused, as allowed by the pin-function table. The motor buck keeps the MCU, voltage reference and brake comparators powered when USB is removed while VMOTOR remains energized; either buck alone must support the full logic load. Verify switchover droop, cold start and no reverse current on the bench.

PP5V is not connected in this sink-only implementation. Power-source operation, power-role swaps and VCONN-role swaps must be disabled in the PD configuration. The PP5V treatment and TPD4S480 behavior if 3.3 V collapses while VBUS remains in EPR require a TI application review and bench validation before release.

### Calculations

| Item | Nominal calculation | Implication |
|---|---|---|
| Logic rail | 1 V × (1 + 100 kΩ / 43.2 kΩ) | 3.315 V before ideal-diode loss; check load drop, reference and tolerance |
| eFuse current limit | 18,000 / 4,020 Ω | 4.478 A nominal; approximately 215 W motor input at 48 V |
| Input UVLO | 1.2 V × (1 + 360 kΩ / 10 kΩ) | 44.4 V nominal; prevents motor operation on SPR or 36 V EPR |
| Input OVP | 1.2 V × (1 + 426.7 kΩ / 10 kΩ) | 52.40 V nominal; calculate full comparator/resistor tolerances |
| Motor ADC scale | (360 kΩ + 20 kΩ) / 20 kΩ | 19:1; 48 V gives 2.526 V |
| Current monitor | approximately 27.9 µA/A × 20 kΩ | approximately 0.558 V/A; calibrate using the U6 datasheet limits |
| Phase shunt | 5.5² × 0.033 Ω | approximately 1.0 W per shunt; selected 3 W parts need copper/thermal verification |
| Bulk energy, 48→53 V | ½ × 940 µF × (53²−48²) | only 0.237 J; bulk capacitors cannot absorb sustained regeneration |
| Brake switch on | 2.5 × (1 + 196 kΩ/10 kΩ + 196 kΩ/1 MΩ) | approximately 51.99 V |
| Brake switch off | above − 3.3 × 200 kΩ/1 MΩ | approximately 51.34 V; nominal 0.66 V hysteresis |
| Motor OVP shutdown | 2.5 × (1 + 430 kΩ/21 kΩ) | approximately 53.69 V; independent of MCU software |
| Initial brake load | 53² / 10 Ω | approximately 281 W while on, 5.3 A; external resistor/heatsink/pulse-energy rating required |

The resistor tolerances, comparator offset, reference error, gate delay, wiring inductance, maximum regenerated power and maximum bus overshoot must be evaluated together. The 60 V motor-driver rating is not a usable transient clamp setting. A generic 51 V TVS can clamp far above 60 V and is not an adequate motor-bus braking strategy.

### Motion and shutdown

U7 drives eight 100 V external MOSFETs and two 33 mΩ phase shunts. Four 470 nF bootstrap capacitors, the charge pump, local 12 V/5 V bypasses and the VCC filter are represented explicitly. Current scaling, gate drive, dead time and chopper settings must be determined from the actual motor and validated waveforms; default register values are not an approved 5.5 A setup.

U8/U9 select native left/right endstop signals in ramp mode or external Step/Dir signals in step mode. The transistor input stages invert their external signals. Open inputs read high; firmware and TMC switch polarity must account for this. The maximum Step/Dir rate has not been qualified.

DRV_EN_N has a pull-up. Its sink path requires two series transistors: MCU_RUN with motor power-good and voltage-good, plus the externally asserted hardware-enable input and U29/U33 temperature permit. Open or grounded hardware enable disables the bridge. This is a functional enable, not a certified safe-torque-off circuit. The motor-side buck sustains this logic while motor capacitors are charged; power-loss disable timing and comparator operation still need bench validation.

The AS5047P is a top-side part at the board origin. Magnet placement, gap and field orientation must be validated for the top-only assembly. Its SPI port shares the bus with TMC5160 and flash; each device has a separate CS and all unselected devices must release MISO. Its ABI outputs remain on labelled service pads; U7 pins23/24 are grounded and pin25 is NC for the selected STEP/DIR mode.

### Interfaces

CAN uses TCAN332 and RS485 uses MAX3485E. Supply bypass and bus ESD parts are included. Fit 120 Ω termination externally only at the two physical ends of each bus; establish RS485 bias at the system level. These are non-isolated interfaces.

RS232 uses MAX3232 at 3.3 V, with its four charge-pump capacitors. J10 USB 2.0 D+/D− has USBLC6-4SC6 shunt ESD protection and MCU-side 22 Ω series resistors. R107/R108 provide a divided and filtered VBUS attach sense on PB0/ADC_IN8: 1 MΩ over 47 kΩ gives about 0.224 V at J10's nominal 5 V. J10 VBUS is independent from the EPR rail. Firmware must keep the USB peripheral detached unless `USB_VBUS_SENSE` indicates present VBUS. Route USB as a 90 Ω differential pair with an uninterrupted reference plane; no impedance claim is made for the current placement.

GPIO/stop/home/Step/Dir inputs use 160 V NPN stages and base-emitter reverse protection. Nominal use is 24 V logic; thresholds and transient immunity are unqualified. Outputs are low-side NPN switches with flyback diodes; begin qualification below 100 mA per channel. J7 pin17 is **the 48 V motor bus**, not a regulated 24 V accessory rail. An accessory requiring 24 V needs a separate supply.

The logic rail is supplied from reverse-blocked USB-derived and motor-derived regulators. TMCL command execution, CANopen CiA profiles, standalone programs and motor tuning are firmware work outside the circuit netlist.

### Layout release requirements

The r0.4 ECO route reinforces the high-current nets with nominal 2.4 mm copper corridors and parallel 0.6/0.3 mm vias. The 1 oz IPC-2221 external-layer screening estimate is 6.12 A at a 20 °C rise. Dense package exits, clipped zone geometry, current sharing between layers and enclosure temperature still require powered thermal validation. Verify the bridge loops, Kelvin shunt returns, charge-pump/bootstrap paths, QFN thermal stitching and eFuse copper against the manufacturers' layout guidance.

The imported CSD19534 footprint contains four vias inside its drain pad. They are now explicitly connected to the drain and the board declares via-in-pad fabrication. Specify filled-and-capped vias; ordinary open holes can wick solder and invalidate assembly assumptions.

### Primary power-part ratings

The [GCT USB4105 specification](https://gct.co/files/specs/usb4105-spec.pdf) rates the connector for 48 V, 5 A on VBUS and 240 W. The [TPS26750 datasheet](https://www.ti.com/lit/ds/symlink/tps26750.pdf), Figure 8-5 and section 8.4.1.2.2.6, define the POWER_PATH_EN two-NMOS buffer; the exact [CSD17484F4](https://www.ti.com/lit/ds/symlink/csd17484f4.pdf) used by TI's EVM is fitted for Q2/Q3. The [LM66100 datasheet](https://www.ti.com/lit/ds/symlink/lm66100.pdf), Figure 17 and section 9.2.2.1, describe the status-interlocked dual-input ORing circuit used for the two logic supplies. These ratings do not validate the assembled PCB.

### Datasheet-based motor assumptions

The ordered [STEPPERONLINE 34HS31-6004S1](https://files.omc-stepperonline.com/34HS31-6004S1_Full_Datasheet.pdf) specifies 6 A/phase, 4.8 Nm holding torque, 1.8-degree steps, 0.48 Ω phase resistance (±10%) and 3.5 mH phase inductance (±20%). The manufacturer rating is not an approved TMC5160 RMS setting. The board's 5.5 A RMS design screen is retained without enabling motion; current waveform, hold current and thermal limits need qualification for this motor.

Rotor inertia is not specified in the cited motor sheet. The previous QSH8618 inertia and kinetic-energy examples are withdrawn; the power audit records unknown energy as null, not zero. The 940 µF bulk bank absorbs only 0.237 J between 48 V and 53 V. Rotor and attached-load inertia, gearing, gravity and stopping time determine braking energy; speed and brake duty cannot be inferred from holding torque. The 10 Ω / 300 W external brake remains a starting specification. See `motor-data.json` for sourced inputs.

The reference-board ECO adds independent USB logic power, board-temperature inhibition and phase-current diagnostics. See [USB and telemetry architecture](usb-pd-architecture.md) for the exact power paths, thresholds, transfer functions and unmeasured USB/thermal limits.

### Driver supply and protection ECO

U34 now regulates VMOTOR to 12 V for U7 VSA/12VOUT and U15. U12 is a REF3425 series reference; the brake and input/motor OVP dividers use reviewed precision resistors. See [power validation](power-validation.md) for tolerance envelopes, order holds and the unperformed bench test matrix. The regenerated ECO has fresh native routing and manufacturing checks; powered system qualification and the order hold remain open.

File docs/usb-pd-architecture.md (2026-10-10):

# USB-C PD, USB data and current-sense architecture

The r0.4 ECO separates PD POWER J1 from USB DATA J10, preserving the original motor-bus backup supply. `scripts/design.test.mjs` checks physical numbered-pin connections in `dist/index/circuit.json`.

## Two independent USB-C ports

J1 and J10 use tscircuit's standard USB-C connector with the exact C3020560 USB4105-GF-A footprint. J1 VBUS is PD_VBUS and J10 VBUS is USB_DATA_VBUS; they are never joined. J1 D+/D− pins are NC. Its SBU contacts use U1's protected SBU channels, whose system-side outputs are NC. J10 powers setup/diagnostics independently through U28 TPS2553 and U25 TLV755. It cannot energize VMOTOR.

U5 derives board logic from PD_VBUS before the eFuse; U22 retains VMOTOR-fed brake backup. U23/U24 OR these supplies into V3V3. U26/U27 combine board V3V3 and DATA-derived V3V3_USB into a separate V3V3_MCU rail. Only STM32, its reset pullup, bypass/bulk capacitors and SWD supply reference use this output. Industrial transceivers, flash, encoder and sensors cannot draw their supply from DATA. R119/R120 sense board V3V3 on PB1; the unused U2 IRQ is NC and PD state is polled. Chip selects are released open-drain into board-domain pullups; peripheral inputs and I²C are high impedance with board power absent.

R113 limits DATA overload current; it does not enforce USB power states. Firmware advertises a bus-powered 500 mA configuration, disarms on suspend, clears commands and stale telemetry, quiesces GPIO/I²C and enters STOP0. RTC wakes the main loop every nominal 50 ms for VBUS sampling and IWDG service. USB resume/reset wakes normally; full clocks return before servicing pending USB interrupts. See `firmware/README.md` for the implementation and mandatory current, wake-latency, detach, inrush, reverse-current and supply-handover bench checks. The 2.5 mA suspend limit is not yet a measured result.

## Power Delivery path

```text
J1 CC1/CC2
  -> U1 TPD4S480 CC short-to-VBUS protection
  -> CC1_PD / CC2_PD
  -> U2 TPS26750 pins 24/25
  -> configured sink-only 48 V / 5 A EPR negotiation
```

The TPS26750 is the dedicated PD controller. TI specifies EPR sink support at 28 V, 36 V and 48 V and shows the PD exchange on CC. U2's optional `USB_P`/`USB_N` pins do not carry board USB data; pins 22 and 23 are grounded as TI requires for unused GPIO4/GPIO5. `POWER_PATH_EN` drives the exact two-NMOS buffer from TI Figure 8-5: R9 (0 Ω) drives Q2, R11 pulls Q2's drain up to `PD_3V3`, R12 (0 Ω) drives Q3, and R13 pulls `PD_PATH_OK` up to `PD_3V3`. Q2/Q3 are the CSD17484F4 devices used by the TPS26750 EVM. `PD_PATH_OK` is then combined with the MCU permit before the TPS26631 eFuse can energize the motor bus.

The board still requires a reviewed TI-generated full-flash configuration image in U3. A blank image leaves the design in SafeMode and does not negotiate 48 V.

## USB 2.0 data and attach path

J10 DP1/DP2 share USB_DP_CONN; DM1/DM2 share USB_DM_CONN. D15 USBLC6-4SC6 protects both data lines and both CC lines, with pin2 GND and pin5 DATA VBUS. R71/R72 remain the 22 Ω series links to U16. C73 provides the 100 nF TVS VBUS bypass. J10 CC1 and CC2 each have their own 5.1 kΩ pulldown; they are not joined to the PD controller.

J10 VBUS feeds R107 1 MΩ / R108 47 kΩ with C72 100 nF, and U16 PB0 senses their junction. At 5 V, nominal ADC voltage is 0.224 V. Firmware scales the divider, enables USB above 4.0 V VBUS, and detaches below 3.0 V. Validate thresholds, ADC error and attach/detach timing on hardware. PD VBUS presence alone must never enable the USB pull-up.

## Motor current and voltage feedback

- U6 TPS26631 pin 13 produces `IIN_MON`; R26 converts it to a voltage and U30 ADS1115 channel 1 reads it.
- The independent VMOTOR divider R31/R32/R33 produces `VMON_ADC`; U30 channel 0 reads it at ±4.096 V full scale. U30 address is 0x49; conversion validity and freshness are checked before motor permission.
- R109 and R110 are independent 33 mΩ, 3 W low-side phase shunts connected to TMC5160A `SRAH` and `SRBH` inputs for phase-current regulation.
- R115/R116 are 5 mΩ, 1 W series shunts in the A1/B1 motor leads. U31/U32 INA240A1 (gain 20) feed STM32 PA0/PA1 through 1 kΩ/10 nF filters. Nominal output is 1.65 V + 0.1 V/A, giving 0.872–2.428 V at the ±7.78 A peak of a 5.5 A RMS sine wave. Each shunt dissipates 0.151 W at 5.5 A RMS. These are calculated targets; ADC reference/zero calibration, PWM settling, negative transients, overload and temperature must be measured. Current firmware reports instantaneous samples, not calibrated RMS current.
- The TMC5160A is intentionally an external-bridge controller. Q6–Q13 are its two full MOSFET bridges, not manual substitutes for an integrated output stage.
- Firmware must calibrate input-current telemetry and configure TMC5160A current scaling, gate drive and chopper behavior for the actual motor. The netlist proves the paths exist; powered validation proves accuracy and stability.

## Temperature and commissioning behavior

U29 TMP102 monitors board temperature near the bridge. Its active-low open-drain ALERT feeds U33, which combines TEMP_OK with the existing watchdog/voltage-window result before RUN_SAFE. Firmware configures a 70 °C threshold and 55 °C hysteresis, reads back the configuration, rejects stale/invalid samples and requests progressive current reduction above 60 °C. Board temperature is not a direct MOSFET junction measurement. The commissioning image keeps motor outputs disabled until the TI configuration and physical motion validation gates are satisfied; it does not claim that a current request has been applied to an energized driver.

The external TMC5160A bridges remain the approved architecture. DRV8462 in the DDV package is a redesign candidate, not an interchangeable replacement; the lower-current DDW/DDW-family reference stage must not be copied into this 5.5 A RMS target without a new power/thermal review.

## Primary references

- [Texas Instruments TPS26750 product page](https://www.ti.com/product/TPS26750)
- [Texas Instruments TPS26750 datasheet](https://www.ti.com/lit/ds/symlink/tps26750.pdf)
- [Texas Instruments TPS26750 EVM user guide](https://www.ti.com/lit/ug/slvucp8a/slvucp8a.pdf)
- [Texas Instruments CSD17484F4 datasheet](https://www.ti.com/lit/ds/symlink/csd17484f4.pdf)
- [Texas Instruments TPD4S480 datasheet](https://www.ti.com/lit/ds/symlink/tpd4s480.pdf)
- [ST USBLC6-4 datasheet](https://www.st.com/resource/en/datasheet/usblc6-4.pdf)
- [STMicroelectronics STM32G0B1CB datasheet](https://www.st.com/resource/en/datasheet/stm32g0b1cb.pdf)
- [USB-IF USB Type-C cable and connector specification](https://www.usb.org/document-library/usb-type-cr-cable-and-connector-specification-release-20)

The PD controller, EEPROM image, cable, source, protection network and powered measurements must all be reviewed before claiming EPR operation on assembled hardware.

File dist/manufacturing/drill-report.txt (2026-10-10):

Drill report for pd1180-epr-r0.3.kicad_pcb
Created on 2026-10-11T02:49:48

Copper Layer Stackup:
    =============================================================
    L1 :  F.Cu                      front
    L2 :  In1.Cu                    in1
    L3 :  In2.Cu                    in2
    L4 :  B.Cu                      back

Drill file 'pd1180-epr-r0.3-PTH.drl' contains
    plated through holes:
    =============================================================
    T1  0.300mm  0.0118"  (628 holes))
    T2  0.700mm  0.0276"  (8 holes)  (with 8 slots)
    T3  0.914mm  0.0360"  (20 holes))
    T4  1.200mm  0.0472"  (4 holes))
    T5  1.800mm  0.0709"  (6 holes))

    Total plated holes count 666

Drill file 'pd1180-epr-r0.3-NPTH.drl' contains
    unplated through holes:
    =============================================================
    T1  0.650mm  0.0256"  (4 holes))
    T2  4.200mm  0.1654"  (4 holes))

    Total unplated holes count 8

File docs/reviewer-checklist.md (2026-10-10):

# PD1180-EPR reviewer checklist

Start with `bun install --frozen-lockfile` and run `bun run review`. Machine checks produce evidence under `docs/`, `routing/` and `release/`; this checklist focuses reviewer time on design decisions and physical risks.

## Requirements and mechanics

- [ ] Product revision, motor model, phase-current target and USB-C PD contract match `hardware-contract.json`.
- [ ] Board outline matches the TMCM-1180 V1.1 stepped 85.9 × 85.9 mm perimeter and all four 4.2 mm mounting holes match the documented asymmetric coordinates.
- [ ] Shaft axis, magnet gap, motor rear-face hardware, standoffs, cable exits and enclosure height have physical drawings or measurements.
- [ ] All fitted parts and service pads are on top; bypass capacitors surround their ICs and the encoder remains centered. Validate the revised encoder-to-magnet gap.
- [ ] Tall bulk capacitors, connectors, brake resistor/heatsink, cable and motor are covered by the mechanical/assembly boundary.

## Schematic

- [ ] `bun run check:schematic-style` reports zero issues and `docs/checks/schematic-style.json` records zero issues for every viewer analysis category.
- [ ] All 16 A4 sheets have a clear function, rail names, connector pin numbers and readable signal flow.
- [ ] Imported pin numbering is checked against manufacturer drawings for USB-C, TPS26750, TPD4S480, TPS26631, TMC5160A, MOSFETs, shunts and connectors.
- [ ] `docs/usb-pd-architecture.md` matches the compiled netlist: J1 carries EPR CC/VBUS, J10 carries USB 2.0 D+/D− with independent CC pulldowns, and only J10 VBUS feeds the attach divider. U22 retains motor-bus brake backup.
- [ ] Reset defaults hold POWER_PERMIT, MCU_RUN and every external driver/output inactive.
- [ ] PD contract, power-good, voltage window and fault signals gate the motor stage independently of a normal firmware command.
- [ ] Every IC supply pin has local bypassing; bulk-capacitance, discharge and reverse-feed paths are explained.
- [ ] Unused pins, shields, exposed pads, test points and external termination requirements are explicit.

## Power, protection and thermal

- [ ] Input/eFuse UVLO, OVP, inrush and current-limit calculations include tolerance and startup state.
- [ ] TPS26631 `IIN_MON` and the independent VMOTOR divider reach ADS1115 channels 1/0 at address 0x49. STM32 PA0/PA1 read INA240 phase-current diagnostics; regulation remains on the TMC5160A's independent 33 mΩ shunts.
- [ ] Kelvin branches join load/ground copper only at the designated shunt terminal; the final native critical-copper check passes. Inspect their lengths and switching-noise exposure as well as DRC.
- [ ] TMP102 at 0x48 inhibits RUN_SAFE through U33. Verify ALERT polarity, 70 °C cutoff, 55 °C re-arm threshold, missing-sensor behavior and board-to-junction temperature correlation on hardware.
- [ ] DATA USB alone powers MCU diagnostics through TPS2553, TLV755 and the second LM66100 OR. Verify board peripherals stay unpowered, chip-select/I²C pins do not backfeed, and suspend/resume invalidates old telemetry. Measure startup, pre-configuration, configured and suspend current; test both-source transitions and reverse current before claiming USB power compliance.
- [ ] Phase-current programming, RMS/peak convention, shunt dissipation and current-sense polarity are consistent.
- [ ] Regeneration energy, the 55 V VS operating limit and 10–13 V external VSA/12VOUT supply range and external brake resistor/heatsink pulse/average ratings are reviewed for the actual load.
- [ ] Connector, cable, via and copper current ratings are checked at enclosure temperature.
- [ ] USB detach, hard reset, cable fault, 3.3 V collapse and residual VMOTOR energy all lead to a safe state.

## Placement and routing

- [ ] Protection parts sit at the connector and high-current/charge-pump/bootstrap loops are compact.
- [ ] Shunt sense connections are Kelvin-routed and cannot be bypassed by load copper.
- [ ] Critical power nets meet the 2.4 mm corridor, 0.16 mm clearance and parallel-via policy.
- [ ] Every via drill is at least 0.30 mm. Approved pad/drill pairs are 0.60/0.30 mm for power/general vias and 0.50/0.30 mm for dense signals; no smaller-drill exceptions.
- [ ] Q4, Q6–Q13 and Q16 each retain exactly four 0.60/0.30 mm drain-pad thermal vias (40 total), with epoxy-filled and copper-capped via-in-pad processing in the quote.
- [ ] U34 retains four 0.60/0.30 mm exposed-pad thermal vias. The current audit and quote cover all 69 via-in-pad locations with filled/capped processing.
- [ ] All 46 final native top-layer IC-to-capacitor paths pass `check:decoupling --native`; see `native-decoupling-check.json`.
- [ ] Ground continuity, return paths, thermal-pad stitching, plane necks and copper-to-edge clearance are visually inspected.
- [ ] USB D+/D− routing has a continuous reference path and the fabricator stack-up/impedance target is reviewed.
- [ ] Product/revision, connector function, polarity/pin 1 and `Made with tscircuit` markings are readable and clear of pads/holes.

## Sourcing and assembly

- [ ] BOM manufacturer part number, package, polarity and exact LCSC code match each imported footprint.
- [ ] Live stock is refreshed immediately before ordering; timestamped evidence is availability information, not a reservation.
- [ ] Alternatives are checked for pinout, voltage/current/temperature rating, package, lifecycle and firmware impact.
- [ ] JLC placement preview is manually reviewed for IC pin 1, diode/capacitor polarity, connector orientation, rotations and centroids.
- [ ] Filled/capped via-in-pad, four layers, 1 oz copper, 1.6 mm thickness and top-side assembly are present in the quote.

## Delivery and bring-up

- [ ] Verify the corrected STEP/DIR pin configuration at U7 pins 23–25 against the routed board; see `step-dir-hardware-review.md`. A clean geometric DRC does not validate mode-dependent pin functions.

- [ ] `bun run review` passes and `release/delivery-manifest.json` matches the exact release files.
- [ ] Gerber, drill, BOM, CPL, KiCad, schematic, 3D, firmware contract and SHA-256 files open successfully.
- [ ] Prototype-order gates and system-validation gates are reported separately.
- [ ] TPS26750 full-flash image and STM32 firmware hashes are recorded before powered motor testing.
- [ ] Bring-up begins current-limited without a motor, then validates rails, PD negotiation, protection, brake, gate drive, current regulation and thermal rise in stages.
- [ ] Production status remains blocked until mechanical fit, programmed operation, thermal, fault, EMC/ESD and load testing have recorded evidence.

Reviewer sign-off should record board revision, commit, release hashes, open risks and the exact evidence used. Do not sign off from screenshots alone.

Engineering review and ordering are separate gates: `bun run review` validates the current source, CAD, firmware, stock and delivery artifacts while retaining any documented order hold. `bun run check:release` additionally requires `fabrication_orderable: true`; it must fail until the order hold is cleared with evidence. A passing review/CI run is not authorization to order or a claim of powered hardware qualification.

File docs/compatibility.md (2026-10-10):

# PD1180-EPR — NEMA 34 Smart Motor-Mounted Stepper Controller with USB-C PD 3.1 EPR

## System compatibility and integration

| Area | PD1180-EPR — NEMA 34 Smart Motor-Mounted Stepper Controller with USB-C PD 3.1 EPR, r0.4 ECO |
|---|---|
| Input power | USB-C PD 3.1 EPR 48 V / 5 A requested contract; the motor output remains inhibited until a valid contract is confirmed |
| Logic power | PD and motor-bus buck OR plus current-limited DATA LDO, reverse-blocked into the shared 3.3 V rail |
| Motor stage | TMC5160A with external MOSFET bridges; 5.5 A RMS phase-current design target |
| USB | J1 PD POWER plus J10 USB DATA; DATA alone powers setup; PD is required for motion, no need for the EPR charger to provide host data |
| Step/Dir | 24 V transistor-conditioned Step and Direction inputs |
| Encoder | Top-side AS5047P aligned at board center, plus labelled ABI service pads |
| Field buses | CAN, RS485 and RS232; bus termination is fitted in the external harness |
| Outputs | Hardware enable and two protected low-side outputs on consolidated J7; pin17 exposes VMOTOR |
| Programming | Top-side SWD service pads for the STM32 and an I2C configuration EEPROM for the PD controller |
| Mechanics | 85.9 × 85.9 mm TMCM-1180 V1.1 stepped outline, four 4.2 mm mounting holes on the documented asymmetric pattern |
| Assembly | All fitted parts and service pads on top; no bottom paste. Through-hole headers and bulk capacitors may require selective or hand soldering. Revalidate the encoder magnet gap and orientation. |

Verify connector polarity, voltage, wire gauge, mating housings and cable keying against [assembly.md](assembly.md) before building a harness.

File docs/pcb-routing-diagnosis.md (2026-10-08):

# PCB routing diagnosis — 2026-10-08

Checked the user-approved source at `8a21b01edc17d7dc3e0f20044361854d1603cbeb`. No schematic, component, net, placement, import or routing source was changed during this investigation.

## Why the source viewer is not routing

1. `tscircuit.config.ts` sets `platformConfig.routingDisabled: true`; `tscircuit.config.json` also sets `build.routingDisabled: true`. `build:preview` explicitly passes `--routing-disabled`. The TSX preview therefore renders only the manually specified local copper, not the final board routing.
2. Enabling routing in an isolated in-memory copy reproduces a separate solver problem. The configured `beta_pipeline7` at effort `5x` stayed in `availableSegmentPointSolver` at 36.36% and was stopped after approximately 6.5 minutes. This was an interrupted diagnostic, not a completed failure result.
3. A comparison using `autorouterVersion="latest"`, effort `1x`, and the same source/placement completed after 554.462 seconds with `aJ ran out of iterations (capacity-autorouter@0.0.958)`. It left 817 `pcb_port_not_connected_error` entries. Increasing the build worker timeout alone does not address this demonstrated iteration-limit error.
4. The enabled-routing diagnostic also reported a local-path error on `BYPASS_C26`: `Via in trace [.U7 > .pin5 to .C26 > .pin1] is misaligned at position {x: 7.249938, y: -0.20000000000000018}`. This is an additional source-route diagnostic; it has not been established as the cause of the solver iteration exhaustion. It does not describe the independently routed KiCad board.

The modern solver input contains 179 connections and 1,310 obstacles on four copper layers. Native source autorouting remains unresolved; no successful fresh tscircuit route is claimed. The runtime configuration was not silently enabled, since that would make the interactive preview run the failing job.

## Existing final PCB route

The existing KiCad board is already routed. A fresh `build:preview` of the approved source followed by `check:routing-fingerprint` passed without updating the saved fingerprint. It matches all 902 ports, 262 placed components, pad geometry, topology and board outline.

- Normalized source fingerprint: `037ae9eaa7d16aa6468e0595aac0d9eca12bd79559e650615f05363e758078c0`
- Routed KiCad board SHA-256: `e2108f83dc67509bc63154ffeee8f314e2f40c017acf4a32cbc8a06b799f7b9d`
- Fresh native KiCad 10.0.5 DRC: **0 violations, 0 unconnected items, 0 schematic-parity issues**. Raw report: [pcb-routing-fresh-drc.json](checks/pcb-routing-fresh-drc.json).

The fresh native check used `pcb drc --all-track-errors --schematic-parity --severity-all --exit-code-violations --refill-zones --format json` against `dist/manufacturing/kicad-project/pd1180-epr-r0.3.kicad_pcb`. It did not save or change the board. This is new DRC evidence, not merely a re-read of the committed report.

Regenerating the viewer in an isolated diagnostic output maps all 902/902 ports and includes 1,264 PCB trace records, 523 vias and 790 copper-pour records. All source schematic entries are preserved. These record counts are converter output, not counts of physical nets. The diagnostic viewer and top/bottom images are saved outside the repository under `../pd1180-routing-audit/`; the versioned manufacturing release was not republished by this investigation.

Exact live supplier checks passed for all 67 populated part codes before this routing work. These checks and PCB DRC do not establish thermal, EMC or powered hardware performance.

## Next routing work

The existing verified copper can be used for PCB viewing while keeping the approved schematic. A requirement to regenerate copper through the tscircuit autorouter needs separate PCB-only work on the local via path and solver/placement input, followed by a successful complete route and native DRC. Do not alter schematic symbols or connectivity, suppress unconnected errors, or refresh the routing fingerprint merely to make a failing route pass.

## Routed preview fix

The source-only `BYPASS_C26` path now has wire contacts at the via coordinate on both layers; `checkTracesAreContiguous` returns zero errors for all local routes. The approved schematic's 2,783 records remain exactly identical.

`bun run build` / `bun run build:pcb` now validates and refreshes the complete routed viewer. `bun run dev` opens that viewer directly, while `index.circuit.tsx` remains the editable source entrypoint and imports remain selectable. The hosted site default also selects the routed viewer. This uses the existing native-DRC-verified copper and does not claim the failed tscircuit solver completed a new route.

Browser verification confirmed the full routed PCB with **0 errors** and successful standalone USB import PCB/schematic switching. No warning was suppressed. This update refreshes the viewer artifact and its hashes; it does not issue a new manufacturing approval.

## Hosted preview output regression (2026-10-08)

Release v0.3.36 at commit `002a0aa` completed its cloud job, but its preview API returned `circuit_json_found: false`. The package contained `release/circuit.json` and `dist/index/circuit.json`, while the configured `previewComponentPath` required **`dist/release/circuit.json`**. The missing selected build output disabled the hosted PCB, schematic, 3D and BOM tabs. A localhost render did not test this contract.

The cloud command now compiles/transpiles the source, then separately builds the verified routed JSON and generates the static site from it. It does not change source schematic records or copper. `check:cloud-package` requires both selected build targets; `check:cloud-package --built` also requires the actual hosted output to exist, contain the routed board and schematic, match the verified artifact exactly, contain no error records and appear in the generated site. The missing-output regression check failed as expected before the corrected build.

The output lookup is documented in the [official tscircuit preview resolver](https://github.com/tscircuit/tscircuit.com/blob/main/fake-snippets-api/routes/api/package_releases/get_preview_circuit_json.ts).

A clean temporary build of the exact cloud command passed with source transpilation, PCB SVG, schematic SVG, 3D PNG and static site generation. The selected output preserves all 12,024 routed records, including 1,264 traces, 523 vias and all 2,783 schematic records, with zero circuit error records. The `--built` check passed; 42 source files (39 imports) remain selectable.

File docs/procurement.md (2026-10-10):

# Procurement snapshot

Exact LCSC-code and package matches only. A fuzzy search result or an unverified package is not accepted as availability evidence. Quantities are for one PCB; stock is a timestamped JLCSearch snapshot and is not reserved JLC assembly inventory.

Last complete refresh: 2026-10-10T21:49:13.191Z.

| LCSC | MPN | Qty/board | Stock | References |
|---|---|---:|---:|---|
| [C1779](https://jlcsearch.tscircuit.com/components/list.json?search=1779) | CL21A475KAQNNNE | 1 | 855873 | C25 |
| [C2482](https://jlcsearch.tscircuit.com/components/list.json?search=2482) | SS110 | 2 | 459251 | D11, D12 |
| [C4184](https://jlcsearch.tscircuit.com/components/list.json?search=4184) | 0603WAF2002T5E | 2 | 2258874 | R26, R33 |
| [C7666](https://jlcsearch.tscircuit.com/components/list.json?search=7666) | SN74LVC1G08DBVR | 4 | 232163 | U4, U10, U11, U33 |
| [C9943](https://jlcsearch.tscircuit.com/components/list.json?search=9943) | MAX3485EESA+T | 1 | 27908 | U20 |
| [C13738](https://jlcsearch.tscircuit.com/components/list.json?search=13738) | X322516MLB4SI | 1 | 172398 | Y1 |
| [C13967](https://jlcsearch.tscircuit.com/components/list.json?search=13967) | CL21B474KBFNNNE | 5 | 211110 | C27, C32, C33, C34, C35 |
| [C14663](https://jlcsearch.tscircuit.com/components/list.json?search=14663) | CC0603KRX7R9BB104 | 41 | 12618106 | C72, C9, C10, C14, C65, C69, C70, C18, C24, C28, C36, C37, C38, C39, C89, C94, C40, C41, C43, C44, C45, C46, C48, C51, C52, C73, C54, C55, C56, C57, C58, C59, C60, C74, C77, C78, C79, C80, C81, C82, C85 |
| [C15725](https://jlcsearch.tscircuit.com/components/list.json?search=15725) | CL10B104KC8NNNC | 7 | 1221863 | C1, C12, C63, C20, C29, C31, C61 |
| [C15846](https://jlcsearch.tscircuit.com/components/list.json?search=15846) | MAX3232ESE+T | 1 | 25896 | U21 |
| [C15849](https://jlcsearch.tscircuit.com/components/list.json?search=15849) | CL10A105KB8NNNC | 8 | 5979916 | C2, C13, C64, C88, C93, C42, C53, C75 |
| [C19666](https://jlcsearch.tscircuit.com/components/list.json?search=19666) | CL10A475KO8NNNC | 1 | 1373603 | C26 |
| [C21189](https://jlcsearch.tscircuit.com/components/list.json?search=21189) | 0603WAF0000T5E | 2 | 6153233 | R9, R12 |
| [C21190](https://jlcsearch.tscircuit.com/components/list.json?search=21190) | 0603WAF1001T5E | 5 | 8013731 | R55, R98, R100, R117, R118 |
| [C22827](https://jlcsearch.tscircuit.com/components/list.json?search=22827) | 0603WAF1803T5E | 4 | 11034 | R19, R20, R31, R32 |
| [C22859](https://jlcsearch.tscircuit.com/components/list.json?search=22859) | 0603WAF100JT5E | 9 | 2873490 | R38, R39, R42, R43, R46, R47, R50, R51, R68 |
| [C22935](https://jlcsearch.tscircuit.com/components/list.json?search=22935) | 0603WAF1004T5E | 1 | 2601258 | R107 |
| [C22939](https://jlcsearch.tscircuit.com/components/list.json?search=22939) | 0603WAF220KT5E | 1 | 11727 | R34 |
| [C23146](https://jlcsearch.tscircuit.com/components/list.json?search=23146) | 0603WAF3603T5E | 1 | 5601 | R27 |
| [C23162](https://jlcsearch.tscircuit.com/components/list.json?search=23162) | 0603WAF4701T5E | 13 | 7433362 | R3, R4, R5, R6, R7, R22, R85, R88, R91, R94, R97, R79, R82 |
| [C23186](https://jlcsearch.tscircuit.com/components/list.json?search=23186) | 0603WAF5101T5E | 2 | 3775920 | R105, R106 |
| [C23345](https://jlcsearch.tscircuit.com/components/list.json?search=23345) | 0603WAF220JT5E | 2 | 2657294 | R71, R72 |
| [C25803](https://jlcsearch.tscircuit.com/components/list.json?search=25803) | 0603WAF1003T5E | 19 | 7990119 | R2, R11, R13, R15, R16, R102, R40, R41, R44, R45, R48, R49, R52, R53, R57, R121, R67, R69, R113 |
| [C25819](https://jlcsearch.tscircuit.com/components/list.json?search=25819) | 0603WAF4702T5E | 8 | 1803082 | R108, R83, R86, R89, R92, R95, R77, R80 |
| [C32677](https://jlcsearch.tscircuit.com/components/list.json?search=32677) | PSM712-LF-T7 | 1 | 317834 | D3 |
| [C37593](https://jlcsearch.tscircuit.com/components/list.json?search=37593) | ADS1115IDGSR | 1 | 14470 | U30 |
| [C38523](https://jlcsearch.tscircuit.com/components/list.json?search=38523) | CL10C120JB8NNNC | 2 | 444842 | C49, C50 |
| [C41095](https://jlcsearch.tscircuit.com/components/list.json?search=41095) | MMBT5551LT1G | 11 | 142386 | Q14, Q15, Q19, Q20, Q21, Q22, Q23, Q17, Q18, Q24, Q25 |
| [C45783](https://jlcsearch.tscircuit.com/components/list.json?search=45783) | CL21A226MAQNNNE | 9 | 1734789 | C15, C16, C17, C66, C67, C68, C90, C91, C92 |
| [C51205](https://jlcsearch.tscircuit.com/components/list.json?search=51205) | CL31B475KBHNNNE | 2 | 17195 | C5, C47 |
| [C55266](https://jlcsearch.tscircuit.com/components/list.json?search=55266) | TPS2553DBVR | 1 | 44248 | U28 |
| [C57112](https://jlcsearch.tscircuit.com/components/list.json?search=57112) | 0603B103K500NT | 2 | 2155057 | C83, C84 |
| [C73651](https://jlcsearch.tscircuit.com/components/list.json?search=73651) | TCAN332DR | 1 | 765 | U19 |
| [C78755](https://jlcsearch.tscircuit.com/components/list.json?search=78755) | BSS123LT1G | 2 | 452190 | Q1, Q5 |
| [C79991](https://jlcsearch.tscircuit.com/components/list.json?search=79991) | M24512-RMN6TP | 1 | 20201 | U3 |
| [C83454](https://jlcsearch.tscircuit.com/components/list.json?search=83454) | SWPA6045S220MT | 2 | 58246 | L1, L2 |
| [C95204](https://jlcsearch.tscircuit.com/components/list.json?search=95204) | RT0603BRD0710KL | 2 | 389486 | R24, R62 |
| [C96446](https://jlcsearch.tscircuit.com/components/list.json?search=96446) | CL10A106MA8NRNC | 5 | 2798959 | C6, C7, C8, C71, C76 |
| [C99269](https://jlcsearch.tscircuit.com/components/list.json?search=99269) | TMP102AIDRLR | 1 | 243 | U29 |
| [C105188](https://jlcsearch.tscircuit.com/components/list.json?search=105188) | TLV3201AIDBVR | 2 | 31358 | U13, U14 |
| [C106210](https://jlcsearch.tscircuit.com/components/list.json?search=106210) | CC0603JRNPO9BN221 | 2 | 386857 | C3, C4 |
| [C107137](https://jlcsearch.tscircuit.com/components/list.json?search=107137) | CC0805KRX7R0BB223 | 1 | 138756 | C30 |
| [C110776](https://jlcsearch.tscircuit.com/components/list.json?search=110776) | RT0603BRD071KL | 1 | 1745 | R66 |
| [C111212](https://jlcsearch.tscircuit.com/components/list.json?search=111212) | USBLC6-4SC6 | 1 | 19079 | D15 |
| [C114200](https://jlcsearch.tscircuit.com/components/list.json?search=114200) | CSD19534Q5A | 10 | 20727 | Q4, Q6, Q7, Q8, Q9, Q10, Q11, Q12, Q13, Q16 |
| [C135822](https://jlcsearch.tscircuit.com/components/list.json?search=135822) | 74LVC1G157GW,125 | 2 | 11325 | U8, U9 |
| [C137720](https://jlcsearch.tscircuit.com/components/list.json?search=137720) | RC0603FR-0743K2L | 2 | 2793 | R17, R103 |
| [C141679](https://jlcsearch.tscircuit.com/components/list.json?search=141679) | RC0603FR-074K02L | 1 | 13 | R25 |
| [C151237](https://jlcsearch.tscircuit.com/components/list.json?search=151237) | SM24CANB-02HTG | 1 | 12464 | D2 |
| [C155214](https://jlcsearch.tscircuit.com/components/list.json?search=155214) | BAV21W-7-F | 8 | 21144 | D1, D6, D7, D8, D9, D10, D4, D5 |
| [C160315](https://jlcsearch.tscircuit.com/components/list.json?search=160315) | B2P-VH(LF)(SN) | 1 | 207876 | J3 |
| [C160317](https://jlcsearch.tscircuit.com/components/list.json?search=160317) | B4P-VH(LF)(SN) | 1 | 65991 | J2 |
| [C170101](https://jlcsearch.tscircuit.com/components/list.json?search=170101) | CL31B225KCHSNNE | 4 | 17939 | C11, C62, C21, C86 |
| [C179173](https://jlcsearch.tscircuit.com/components/list.json?search=179173) | W25Q32JVSSIQ | 1 | 70003 | U17 |
| [C187836](https://jlcsearch.tscircuit.com/components/list.json?search=187836) | REF3425IDBVR | 1 | 8012 | U12 |
| [C191027](https://jlcsearch.tscircuit.com/components/list.json?search=191027) | UCC27511DBVR | 1 | 3141 | U15 |
| [C326730](https://jlcsearch.tscircuit.com/components/list.json?search=326730) | RT0603BRD071ML | 1 | 76218 | R63 |
| [C326731](https://jlcsearch.tscircuit.com/components/list.json?search=326731) | RT0603BRD07180KL | 1 | 17 | R60 |
| [C404027](https://jlcsearch.tscircuit.com/components/list.json?search=404027) | TLV75533PDBVR | 1 | 20831 | U25 |
| [C407954](https://jlcsearch.tscircuit.com/components/list.json?search=407954) | EEUFR1J471 | 2 | 340 | C22, C23 |
| [C471521](https://jlcsearch.tscircuit.com/components/list.json?search=471521) | B20B-PHDSS(LF)(SN) | 1 | 1457 | J7 |
| [C513710](https://jlcsearch.tscircuit.com/components/list.json?search=513710) | CC0805KKX7R0BB224 | 1 | 35814 | C87 |
| [C516354](https://jlcsearch.tscircuit.com/components/list.json?search=516354) | TMC5160A-TA-T | 1 | 9729 | U7 |
| [C705777](https://jlcsearch.tscircuit.com/components/list.json?search=705777) | RT0603BRD07422KL | 1 | 405 | R23 |
| [C720477](https://jlcsearch.tscircuit.com/components/list.json?search=720477) | TS-1088-AR02016 | 1 | 877449 | SW1 |
| [C723637](https://jlcsearch.tscircuit.com/components/list.json?search=723637) | RT0603BRD0720KL | 1 | 121239 | R65 |
| [C844918](https://jlcsearch.tscircuit.com/components/list.json?search=844918) | CRCW060310K0FKEA | 33 | 150167 | R1, R14, R18, R104, R111, R21, R28, R29, R30, R35, R36, R37, R54, R56, R58, R70, R73, R74, R84, R87, R90, R93, R96, R75, R76, R78, R81, R99, R101, R119, R120, R112, R114 |
| [C860148](https://jlcsearch.tscircuit.com/components/list.json?search=860148) | RT0603BRB0716KL | 1 | 3400 | R61 |
| [C861400](https://jlcsearch.tscircuit.com/components/list.json?search=861400) | RT0603BRD07430KL | 1 | 4170 | R64 |
| [C861611](https://jlcsearch.tscircuit.com/components/list.json?search=861611) | RT0603BRD079K09L | 1 | 649 | R122 |
| [C962063](https://jlcsearch.tscircuit.com/components/list.json?search=962063) | AS5047P-ATSM | 1 | 1749 | U18 |
| [C1850273](https://jlcsearch.tscircuit.com/components/list.json?search=1850273) | TPS26631RGER | 1 | 63 | U6 |
| [C1858393](https://jlcsearch.tscircuit.com/components/list.json?search=1858393) | LMR36510ADDAR | 3 | 1663 | U5, U22, U34 |
| [C2047110](https://jlcsearch.tscircuit.com/components/list.json?search=2047110) | SRP7050TA-470M | 1 | 801 | L3 |
| [C2060769](https://jlcsearch.tscircuit.com/components/list.json?search=2060769) | INA240A1DR | 2 | 30852 | U31, U32 |
| [C2847904](https://jlcsearch.tscircuit.com/components/list.json?search=2847904) | STM32G0B1CBT6 | 1 | 775 | U16 |
| [C2862245](https://jlcsearch.tscircuit.com/components/list.json?search=2862245) | CSD17484F4 | 2 | 3261 | Q2, Q3 |
| [C2869734](https://jlcsearch.tscircuit.com/components/list.json?search=2869734) | LM66100DCKR | 4 | 7533 | U23, U24, U26, U27 |
| [C2985721](https://jlcsearch.tscircuit.com/components/list.json?search=2985721) | HoLLR2512-3W-33mR-1% | 2 | 25283 | R109, R110 |
| [C3020560](https://jlcsearch.tscircuit.com/components/list.json?search=3020560) | USB4105-GF-A | 2 | 11505 | J1, J10 |
| [C7419996](https://jlcsearch.tscircuit.com/components/list.json?search=7419996) | FRM121WFR005TM | 2 | 585157 | R115, R116 |
| [C42166327](https://jlcsearch.tscircuit.com/components/list.json?search=42166327) | TPS26750SRSMR | 1 | 517 | U2 |
| [C43131250](https://jlcsearch.tscircuit.com/components/list.json?search=43131250) | TPD4S480RUKR | 1 | 3323 | U1 |

All 83 selected PCB part types (294 placements) had sufficient reported stock for 5 boards at the timestamp above, and all 83 supplier package names matched the pinned manifest expectation.

## Substitution policy

See `alternatives.json` for checked candidates and whether they are package-compatible, need electrical/thermal review, or require a redesign. No alternative is silently selected. All selected primary PCB parts are currently available.

## External system items

The motor, shaft magnet, 48 V EPR source, 5 A EPR cable, mating harness and braking resistor/heatsink are separate system items. The external braking resistor is load-dependent and remains a system-level sizing and procurement gate.

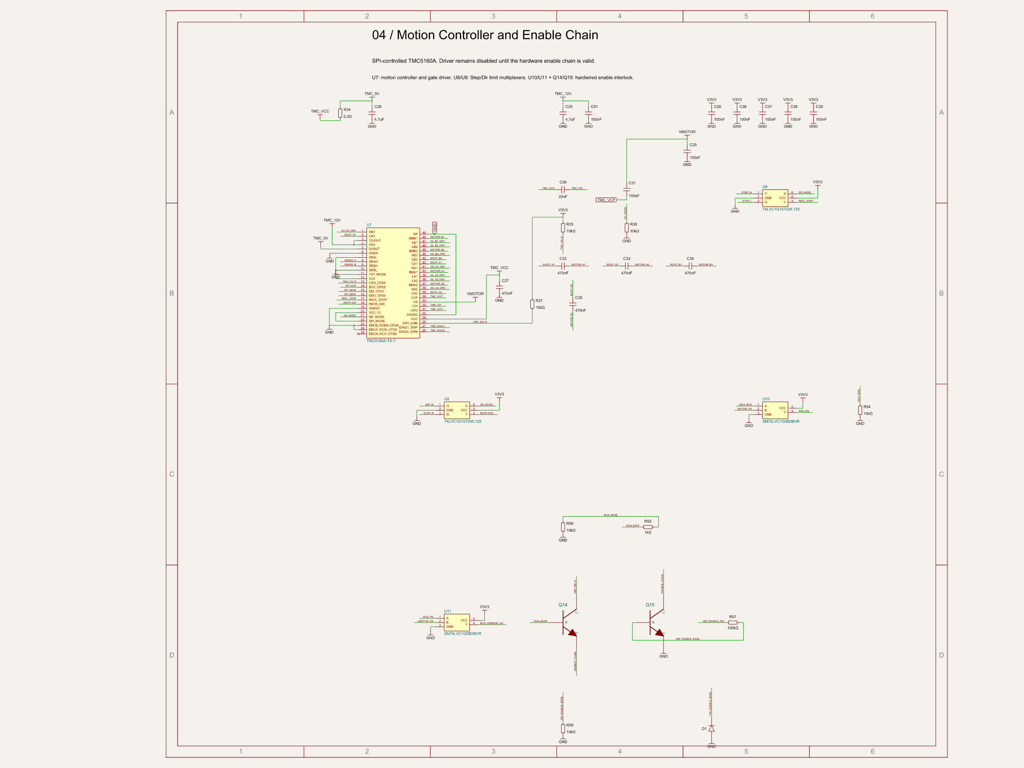
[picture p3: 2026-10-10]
dist/schematics/motion.png

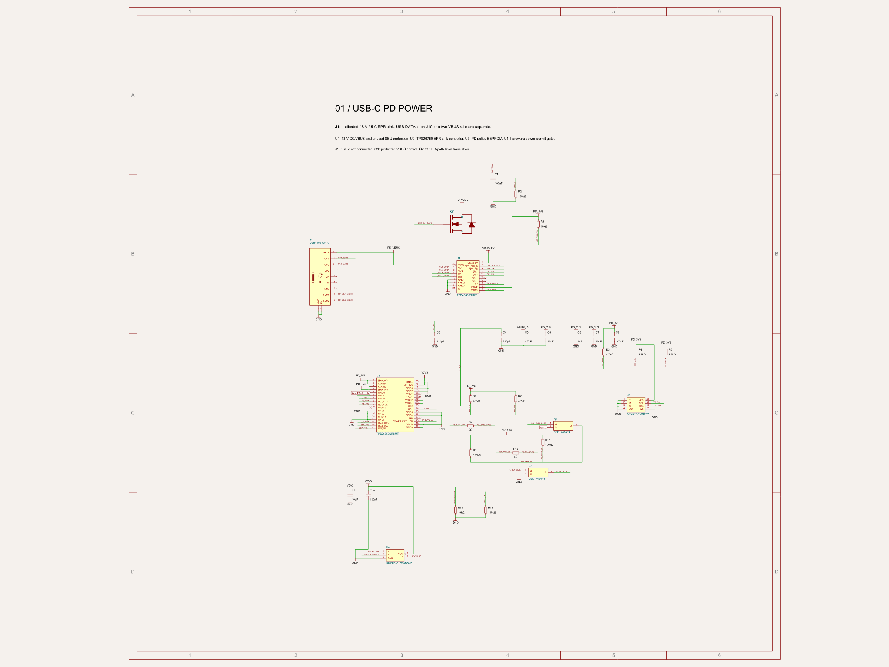
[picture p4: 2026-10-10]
dist/schematics/usb-pd.png

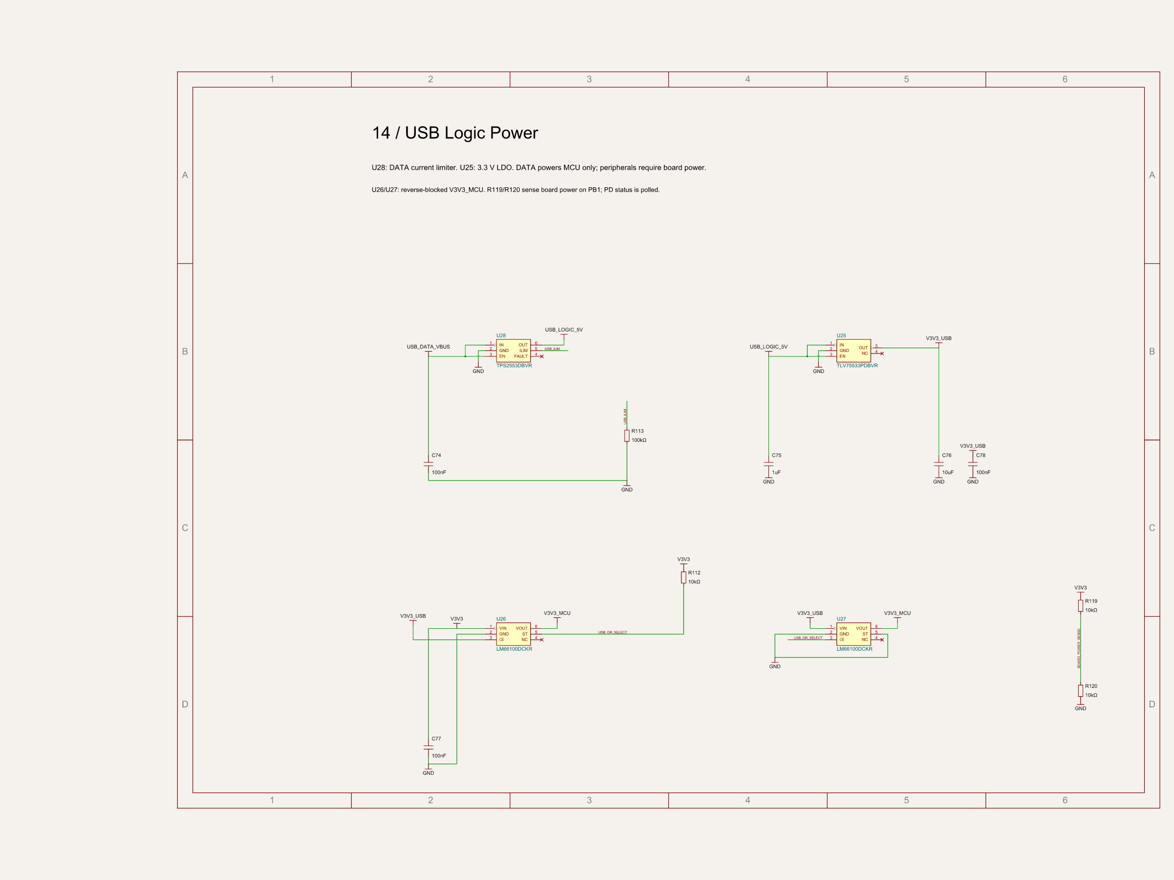
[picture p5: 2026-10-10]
dist/schematics/usb-logic.png

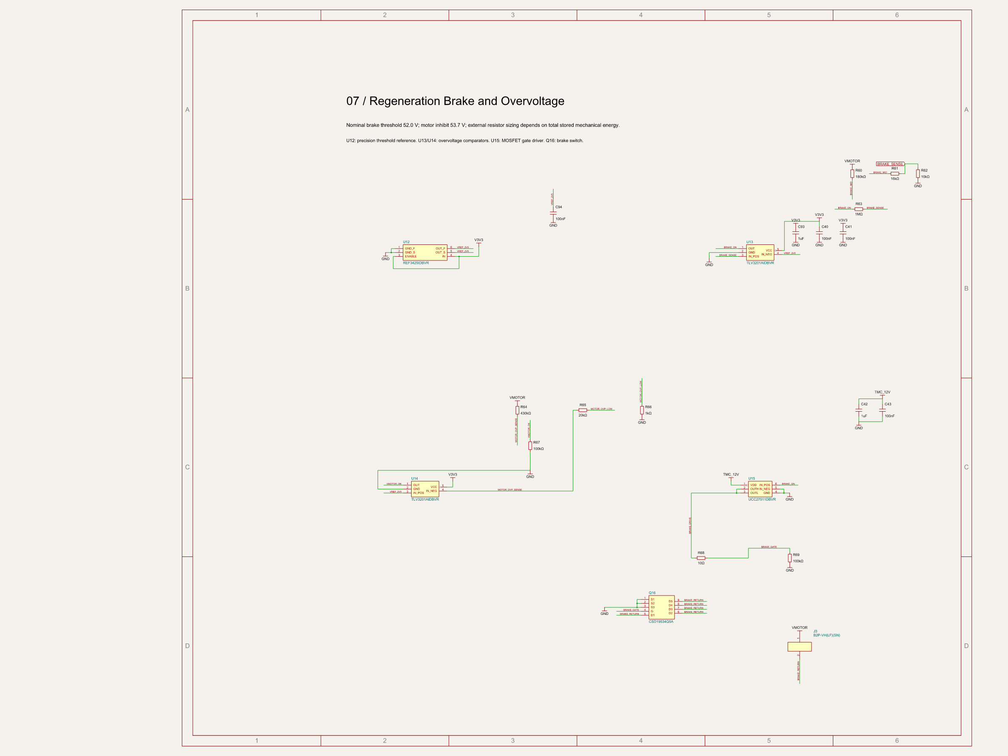
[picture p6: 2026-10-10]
dist/schematics/brake.png

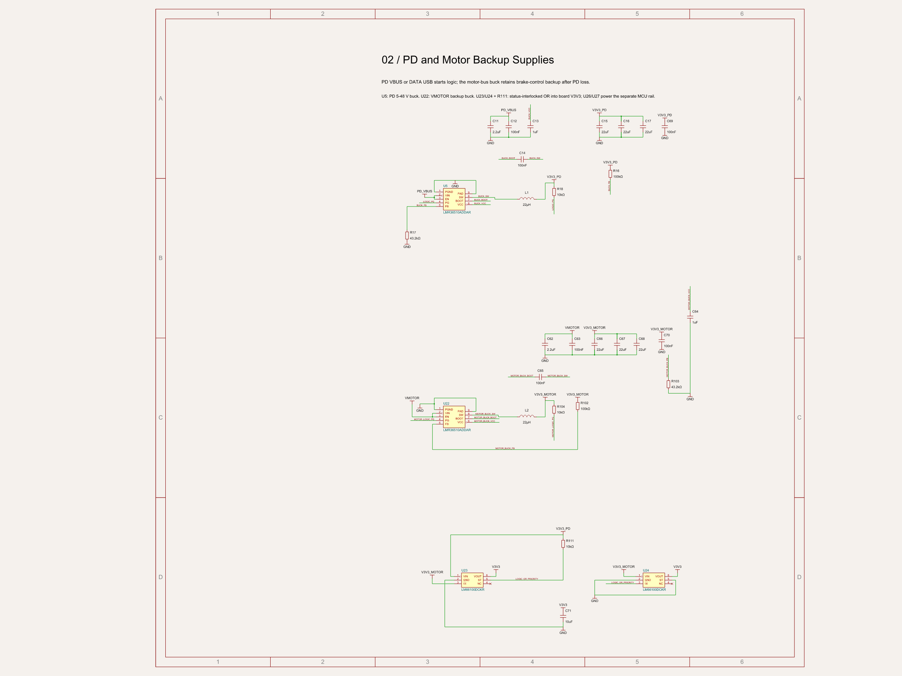
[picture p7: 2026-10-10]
dist/schematics/logic-power.png

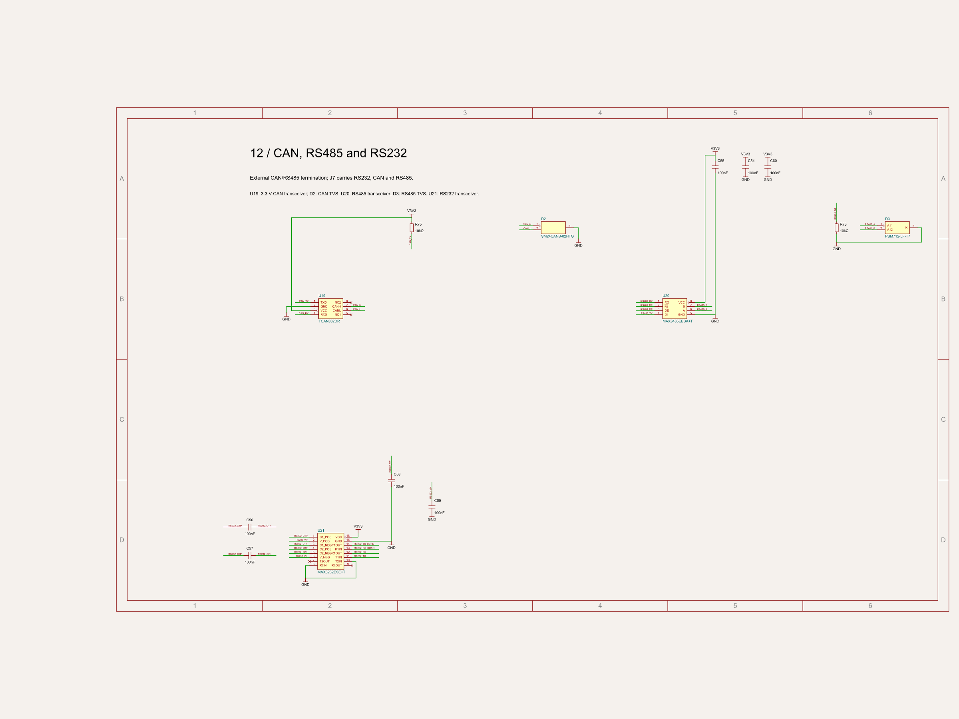
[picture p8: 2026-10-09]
dist/schematics/serial.png

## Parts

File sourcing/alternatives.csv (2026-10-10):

Primary LCSC | Alternative LCSC | MPN | Package | Stock | Status | Reason
C1850273 | C1850281 | TPS26631RGET | VQFN-24(4x4) | 23 | available | TPS26631RGET: same RGE footprint, alternate tape quantity; verify ordering suffix and assembly availability.
C114200 | C2876530 | CSD19534Q5AT | VSONP-8(5x6) | 69 | available | CSD19534Q5AT: same MOSFET/package, alternate tape quantity.
C2862245 |  |  |  |  | no-drop-in-selected | No verified drop-in replacement is approved for the TPS26750 POWER_PATH_EN buffer. CSD17484F4 is the exact TI EVM device; any substitute needs a guaranteed low RDS(on) at 2.5-3.6 V, the same PicoStar-3 pinout/land pattern, leakage review and a PCB recheck.
C105188 | C83561 | TLV3201AIDBVT | SOT-23-5 | 43 | available | TLV3201AIDBVT: same DBV package, alternate reel quantity.
C187836 | C60864 | ADR3425ARJZ-R7 | SOT-23-6 | 4592 | available | 2.5 V reference with matching six-pin force/sense/enable pinout: 1 GND_FORCE, 2 GND_SENSE, 3 ENABLE, 4 VIN, 5 OUT_SENSE, 6 OUT_FORCE. Input range 2.7-5.5 V accommodates the 3.3 V rail. Initial accuracy 0.1% and drift 8 ppm/C are worse than REF3425; brake/OVP tolerance calculations, output-capacitor stability and startup must be requalified before substitution. No automatic substitution or current threshold approval.
C15846 | C143435 | MAX3232ESE+ | SOIC-16 | 3502 | available | MAX3232ESE+: same device/package; shipping format differs.
C79991 | C7561 | M24512-WMN6TP | SOIC-8 | 2567 | available | M24512-WMN6TP: higher minimum supply than R version; 3.3 V application is suitable, verify write timing and temperature grade.
C2985721 | C2903495 | HoJLR2512-3W-33mR-1% | 2512 | 4980 | available | HoJLR2512 33 mOhm 3 W 1%: compare pad geometry, pulse rating and TCR; not an automatic substitute.
C844918 | C2906982 | FRC0603F1002TS | 0603 | 10334802 | available | FRC0603F1002TS: 10 kOhm 1% 0603; verify working voltage, power rating and TCR for each use.
C42166327 | C24833806 | HUSB238A-BB001-QN16R | QFN-16L-EP(3x3) | 1300 | available | HUSB238A-BB001-QN16R is an architectural candidate, not pin/software compatible. Its VBUS handling and 48 V EPR configuration need a complete redesign and documentation review.
C516354 | C1161714 | TMC5160A-WA | QFN-56-EP(8x8) | 2 | available | TMC5160A-WA is a different package; requires a new footprint and layout. Very low observed stock, not a robust procurement fallback.
C43131250 |  |  |  |  | no-drop-in-selected | No verified drop-in replacement for TPD4S480 was selected. Do not substitute a 20 V CC protector in a 48 V EPR design.
C141679 | C705781 | RT0603BRD074K02L | 0603 | 43346 | available | 4.02 kOhm, 0603, 0.1%, 100 mW, 25 ppm/degC candidate for R25; tighter tolerance than the primary 1%. Confirm manufacturer land pattern and actual assembler inventory. The API power_watts numeric field is mis-scaled; 100 mW comes from the attributes text.

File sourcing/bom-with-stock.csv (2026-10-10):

LCSC | MPN | Value | Package | References | Qty/board | Stock | Status | Checked at
C1779 | CL21A475KAQNNNE | 4.7uF | 0805 | C25 | 1 | 855873 | available | 2026-10-10T22:23:44.720Z
C2482 | SS110 |  | SMA(DO-214AC) | D11 D12 | 2 | 459251 | available | 2026-10-10T22:23:48.252Z
C4184 | 0603WAF2002T5E | 20k | 0603 | R26 R33 | 2 | 2258874 | available | 2026-10-10T22:23:44.398Z
C7666 | SN74LVC1G08DBVR |  | SOT-23-5 | U4 U10 U11 U33 | 4 | 232163 | available | 2026-10-10T22:23:43.231Z
C9943 | MAX3485EESA+T |  | SOIC-8 | U20 | 1 | 27908 | available | 2026-10-10T22:23:47.809Z
C13738 | X322516MLB4SI |  | SMD3225-4P | Y1 | 1 | 172398 | available | 2026-10-10T22:23:46.910Z
C13967 | CL21B474KBFNNNE | 470nF | 0805 | C27 C32 C33 C34 C35 | 5 | 211110 | available | 2026-10-10T22:23:44.961Z
C14663 | CC0603KRX7R9BB104 | 100nF | 0603 | C72 C9 C10 C14 C65 C69 C70 C18 C24 C28 C36 C37 C38 C39 C89 C94 C40 C41 C43 C44 C45 C46 C48 C51 C52 C73 C54 C55 C56 C57 C58 C59 C60 C74 C77 C78 C79 C80 C81 C82 C85 | 41 | 12618106 | available | 2026-10-10T22:23:41.952Z
C15725 | CL10B104KC8NNNC | 100nF | 0603 | C1 C12 C63 C20 C29 C31 C61 | 7 | 1221863 | available | 2026-10-10T22:23:42.350Z
C15846 | MAX3232ESE+T |  | SO-Narrow-16 | U21 | 1 | 25896 | available | 2026-10-10T22:23:47.987Z
C15849 | CL10A105KB8NNNC | 1uF | 0603 | C2 C13 C64 C88 C93 C42 C53 C75 | 8 | 5979916 | available | 2026-10-10T22:23:42.337Z
C19666 | CL10A475KO8NNNC | 4.7uF | 0603 | C26 | 1 | 1373603 | available | 2026-10-10T22:23:44.837Z
C21189 | 0603WAF0000T5E | 0 | 0603 | R9 R12 | 2 | 6153233 | available | 2026-10-10T22:23:43.222Z
C21190 | 0603WAF1001T5E | 1k | 0603 | R55 R98 R100 R117 R118 | 5 | 8013731 | available | 2026-10-10T22:23:45.359Z
C22827 | 0603WAF1803T5E | 180k | 0603 | R19 R20 R31 R32 | 4 | 11034 | available | 2026-10-10T22:23:43.983Z
C22859 | 0603WAF100JT5E | 10 | 0603 | R38 R39 R42 R43 R46 R47 R50 R51 R68 | 9 | 2873490 | available | 2026-10-10T22:23:45.162Z
C22935 | 0603WAF1004T5E | 1M | 0603 | R107 | 1 | 2601258 | available | 2026-10-10T22:23:41.886Z
C22939 | 0603WAF220KT5E | 2.2 | 0603 | R34 | 1 | 11727 | available | 2026-10-10T22:23:44.796Z
C23146 | 0603WAF3603T5E | 360k | 0603 | R27 | 1 | 5601 | available | 2026-10-10T22:23:44.351Z
C23162 | 0603WAF4701T5E | 4.7k | 0603 | R3 R4 R5 R6 R7 R22 R85 R88 R91 R94 R97 R79 R82 | 13 | 7433362 | available | 2026-10-10T22:23:43.181Z
C23186 | 0603WAF5101T5E | 5.1k | 0603 | R105 R106 | 2 | 3775920 | available | 2026-10-10T22:23:47.431Z
C23345 | 0603WAF220JT5E | 22 | 0603 | R71 R72 | 2 | 2657294 | available | 2026-10-10T22:23:46.979Z
C25803 | 0603WAF1003T5E | 100k | 0603 | R2 R11 R13 R15 R16 R102 R40 R41 R44 R45 R48 R49 R52 R53 R57 R121 R67 R69 R113 | 19 | 7990119 | available | 2026-10-10T22:23:42.766Z
C25819 | 0603WAF4702T5E | 47k | 0603 | R108 R83 R86 R89 R92 R95 R77 R80 | 8 | 1803082 | available | 2026-10-10T22:23:41.950Z
C32677 | PSM712-LF-T7 |  | SOT-23 | D3 | 1 | 317834 | available | 2026-10-10T22:23:47.814Z
C37593 | ADS1115IDGSR |  | VSSOP-10 | U30 | 1 | 14470 | available | 2026-10-10T22:23:48.403Z
C38523 | CL10C120JB8NNNC | 12pF | 0603 | C49 C50 | 2 | 444842 | available | 2026-10-10T22:23:46.962Z
C41095 | MMBT5551LT1G |  | SOT-23 | Q14 Q15 Q19 Q20 Q21 Q22 Q23 Q17 Q18 Q24 Q25 | 11 | 142386 | available | 2026-10-10T22:23:45.651Z
C45783 | CL21A226MAQNNNE | 22uF | 0805 | C15 C16 C17 C66 C67 C68 C90 C91 C92 | 9 | 1734789 | available | 2026-10-10T22:23:43.612Z
C51205 | CL31B475KBHNNNE | 4.7uF | 1206 | C5 C47 | 2 | 17195 | available | 2026-10-10T22:23:42.726Z
C55266 | TPS2553DBVR |  | SOT-23-6 | U28 | 1 | 44248 | available | 2026-10-10T22:23:48.172Z
C57112 | 0603B103K500NT | 10nF | 0603 | C83 C84 | 2 | 2155057 | available | 2026-10-10T22:23:48.568Z
C73651 | TCAN332DR |  | SOIC-8 | U19 | 1 | 765 | available | 2026-10-10T22:23:47.812Z
C78755 | BSS123LT1G |  | SOT-23 | Q1 Q5 | 2 | 452190 | available | 2026-10-10T22:23:42.273Z
C79991 | M24512-RMN6TP |  | SOIC-8 | U3 | 1 | 20201 | available | 2026-10-10T22:23:42.865Z
C83454 | SWPA6045S220MT |  | SMD,6x6mm | L1 L2 | 2 | 58246 | available | 2026-10-10T22:23:43.593Z
C95204 | RT0603BRD0710KL | 10k | 0603 | R24 R62 | 2 | 389486 | available | 2026-10-10T22:23:44.071Z
C96446 | CL10A106MA8NRNC | 10uF | 0603 | C6 C7 C8 C71 C76 | 5 | 2798959 | available | 2026-10-10T22:23:42.751Z
C99269 | TMP102AIDRLR |  | SOT-563 | U29 | 1 | 243 | available | 2026-10-10T22:23:48.185Z
C105188 | TLV3201AIDBVR |  | SOT-23-5 | U13 U14 | 2 | 31358 | available | 2026-10-10T22:23:46.035Z
C106210 | CC0603JRNPO9BN221 | 220pF | 0603 | C3 C4 | 2 | 386857 | available | 2026-10-10T22:23:42.353Z
C107137 | CC0805KRX7R0BB223 | 22nF | 0805 | C30 | 1 | 138756 | available | 2026-10-10T22:23:44.903Z
C110776 | RT0603BRD071KL | 1k | 0603 | R66 | 1 | 1745 | available | 2026-10-10T22:23:46.516Z
C111212 | USBLC6-4SC6 | USBLC6-4SC6 | SOT-23-6L | D15 | 1 | 19079 | available | 2026-10-10T22:23:47.611Z
C114200 | CSD19534Q5A |  | SON-8(5x6) | Q4 Q6 Q7 Q8 Q9 Q10 Q11 Q12 Q13 Q16 | 10 | 20727 | available | 2026-10-10T22:23:43.974Z
C135822 | 74LVC1G157GW,125 |  | SOT-363-6 | U8 U9 | 2 | 11325 | available | 2026-10-10T22:23:45.356Z
C137720 | RC0603FR-0743K2L | 43.2k | 0603 | R17 R103 | 2 | 2793 | available | 2026-10-10T22:23:43.663Z
C141679 | RC0603FR-074K02L | 4.02k | 0603 | R25 | 1 | 13 | available | 2026-10-10T22:23:44.342Z
C151237 | SM24CANB-02HTG |  | SOT-23 | D2 | 1 | 12464 | available | 2026-10-10T22:23:47.802Z
C155214 | BAV21W-7-F |  | SOD-123 | D1 D6 D7 D8 D9 D10 D4 D5 | 8 | 21144 | available | 2026-10-10T22:23:45.559Z
C160315 | B2P-VH(LF)(SN) |  | 插件,P=3.96mm | J3 | 1 | 207876 | available | 2026-10-10T22:23:46.835Z
C160317 | B4P-VH(LF)(SN) |  | 插件,P=3.96mm | J2 | 1 | 65991 | available | 2026-10-10T22:23:45.199Z
C170101 | CL31B225KCHSNNE | 2.2uF | 1206 | C11 C62 C21 C86 | 4 | 17939 | available | 2026-10-10T22:23:43.609Z
C179173 | W25Q32JVSSIQ |  | SOIC-8-208mil | U17 | 1 | 70003 | available | 2026-10-10T22:23:47.355Z
C187836 | REF3425IDBVR | REF3425IDBVR | SOT-23-6 | U12 | 1 | 8012 | available | 2026-10-10T22:23:45.949Z
C191027 | UCC27511DBVR |  | SOT-23-6 | U15 | 1 | 3141 | available | 2026-10-10T22:23:46.580Z
C326730 | RT0603BRD071ML | 1M | 0603 | R63 | 1 | 76218 | available | 2026-10-10T22:23:46.380Z
C326731 | RT0603BRD07180KL | 180k | 0603 | R60 | 1 | 17 | available | 2026-10-10T22:23:46.136Z
C404027 | TLV75533PDBVR |  | SOT-23-5 | U25 | 1 | 20831 | available | 2026-10-10T22:23:48.184Z
C407954 | EEUFR1J471 |  | 插件,D12.5xL25mm | C22 C23 | 2 | 340 | available | 2026-10-10T22:23:44.519Z
C471521 | B20B-PHDSS(LF)(SN) | B20B-PHDSS(LF)(SN) | 插件,P=2mm | J7 | 1 | 1457 | available | 2026-10-10T22:23:47.416Z
C513710 | CC0805KKX7R0BB224 | 220nF | 0805 | C87 | 1 | 35814 | available | 2026-10-10T22:23:45.741Z
C516354 | TMC5160A-TA-T |  | TQFP-48-EP(7x7) | U7 | 1 | 9729 | available | 2026-10-10T22:23:44.522Z
C705777 | RT0603BRD07422KL | 422k | 0603 | R23 | 1 | 405 | available | 2026-10-10T22:23:44.136Z
C720477 | TS-1088-AR02016 |  | SMD,4x3mm | SW1 | 1 | 877449 | available | 2026-10-10T22:23:47.224Z
C723637 | RT0603BRD0720KL | 20k | 0603 | R65 | 1 | 121239 | available | 2026-10-10T22:23:46.520Z
C844918 | CRCW060310K0FKEA | 10k | 0603 | R1 R14 R18 R104 R111 R21 R28 R29 R30 R35 R36 R37 R54 R56 R58 R70 R73 R74 R84 R87 R90 R93 R96 R75 R76 R78 R81 R99 R101 R119 R120 R112 R114 | 33 | 150167 | available | 2026-10-10T22:23:42.765Z
C860148 | RT0603BRB0716KL | 16k | 0603 | R61 | 1 | 3400 | available | 2026-10-10T22:23:46.194Z
C861400 | RT0603BRD07430KL | 430k | 0603 | R64 | 1 | 4170 | available | 2026-10-10T22:23:46.475Z
C861611 | RT0603BRD079K09L | 9.09k | 0603 | R122 | 1 | 649 | available | 2026-10-10T22:23:46.009Z
C962063 | AS5047P-ATSM |  | TSSOP-14 | U18 | 1 | 1749 | available | 2026-10-10T22:23:47.327Z
C1850273 | TPS26631RGER |  | VQFN-24(4x4) | U6 | 1 | 63 | available | 2026-10-10T22:23:43.974Z
C1858393 | LMR36510ADDAR |  | SOP-8-EP | U5 U22 U34 | 3 | 1663 | available | 2026-10-10T22:23:43.310Z
C2047110 | SRP7050TA-470M | 47uH | SMD,7.3x6.6mm | L3 | 1 | 801 | available | 2026-10-10T22:23:45.568Z
C2060769 | INA240A1DR |  | SOIC-8 | U31 U32 | 2 | 30852 | available | 2026-10-10T22:23:48.591Z
C2847904 | STM32G0B1CBT6 |  | LQFP-48(7x7) | U16 | 1 | 775 | available | 2026-10-10T22:23:46.939Z
C2862245 | CSD17484F4 |  | PicoStar-3 | Q2 Q3 | 2 | 3261 | available | 2026-10-10T22:23:43.131Z
C2869734 | LM66100DCKR |  | SC-70-6 | U23 U24 U26 U27 | 4 | 7533 | available | 2026-10-10T22:23:43.684Z
C2985721 | HoLLR2512-3W-33mR-1% |  | 2512 | R109 R110 | 2 | 25283 | available | 2026-10-10T22:23:45.178Z
C3020560 | USB4105-GF-A |  | SMD | J1 J10 | 2 | 11505 | available | 2026-10-10T22:23:41.954Z
C7419996 | FRM121WFR005TM | 0.005 | 1206 | R115 R116 | 2 | 585157 | available | 2026-10-10T22:23:48.568Z
C42166327 | TPS26750SRSMR |  | VQFN-32-EP(4x4) | U2 | 1 | 517 | available | 2026-10-10T22:23:42.271Z
C43131250 | TPD4S480RUKR |  | QFN-20(3x3) | U1 | 1 | 3323 | available | 2026-10-10T22:23:41.890Z

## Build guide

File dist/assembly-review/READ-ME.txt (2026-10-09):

Engineering top-side assembly package. Origin is the board center. Through-hole parts are included and may require separate assembly. Confirm top-side rotations, polarity, encoder orientation and connector insertion direction with the assembler; see docs/assembly.md.

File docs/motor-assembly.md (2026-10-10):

# Ordered 34HS31-6004S1 motor assembly

The user confirmed the ordered motor on 2026-10-11: **STEPPERONLINE 34HS31-6004S1**, Amazon ASIN **B091C83HWF**. This supersedes the earlier QSH8618 selection. The manufacturer specifies 4.8 Nm holding torque, 6 A/phase, an 86 mm frame, 80 mm maximum body length and a single Ø14 × 32 mm front shaft. The phase-current rating is not an approved driver RMS setting.

The [manufacturer STEP](https://files.omc-stepperonline.com/34HS31-6004S1.STEP) is preserved inside `engineering/mechanical/34HS31-6004S1-manufacturer.zip` as `34HS31-6004S1.step`, SHA-256 `675e55f1d50271255bbd058d8c2e867ecced44b194ded1586c63da77ce1c8a19`. The [datasheet](https://files.omc-stepperonline.com/34HS31-6004S1_Full_Datasheet.pdf) is preserved in the same archive; `motor-data.json` records its hash and electrical inputs. The superseded QSH files remain available in Git history. The archive preserves the original manufacturer bytes while keeping the cloud import within its payload limit.

**Direct rear PCB mounting and rear encoder attachment are not established.** The documented mounting interface is the front flange. Existing rear case fasteners are not approved accessory threads; do not remove them or drill the motor based on this preview.

The default hosted 3D view includes the exact motor, routed PCB and adapter proposal. Open `motor-assembly.circuit.tsx` for the source mechanical fit study. It uses `assembly.subassembly` and the manufacturer STEP converted to GLB. Orange cylinders represent maximum screw-head/washer envelopes. No encoder holder or magnet is modeled for this motor. Custom supports are **proposals, not fabrication-released hardware**. `release/circuit.json` remains the authoritative routed PCB view and now also includes the two mechanical models. Its generator rejects any assembly change to the verified board records. Model URLs are pinned to an immutable Git commit and checked against the local CAD hashes; no moving branch URL is used.

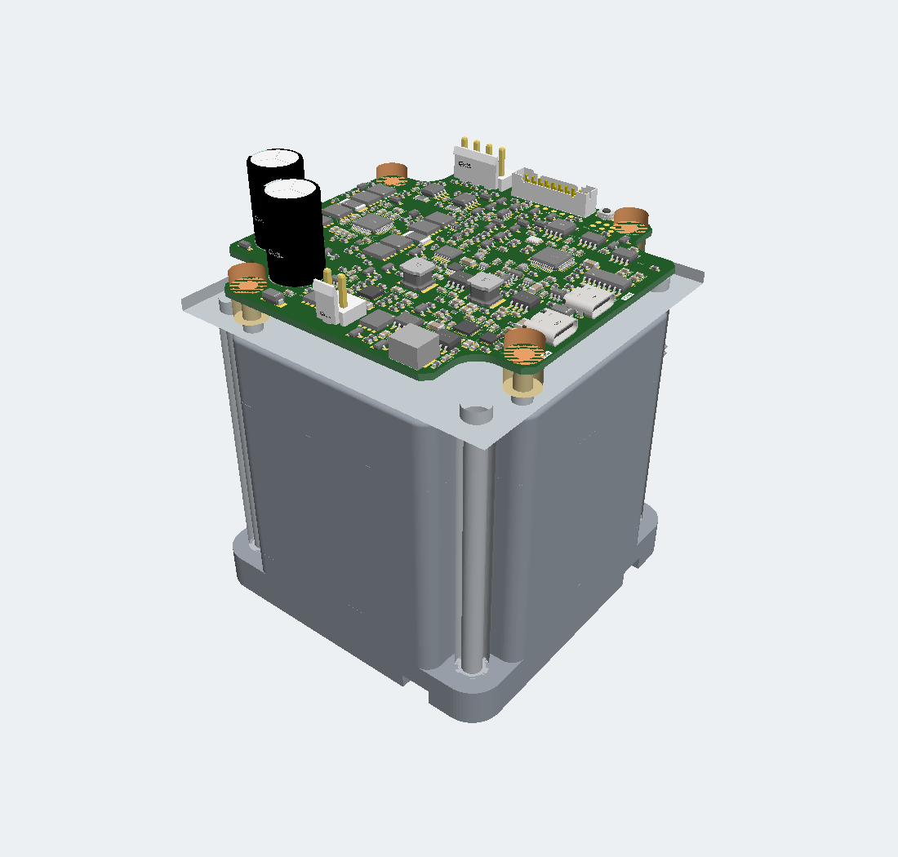
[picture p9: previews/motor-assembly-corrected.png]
Ordered motor assembly proposal


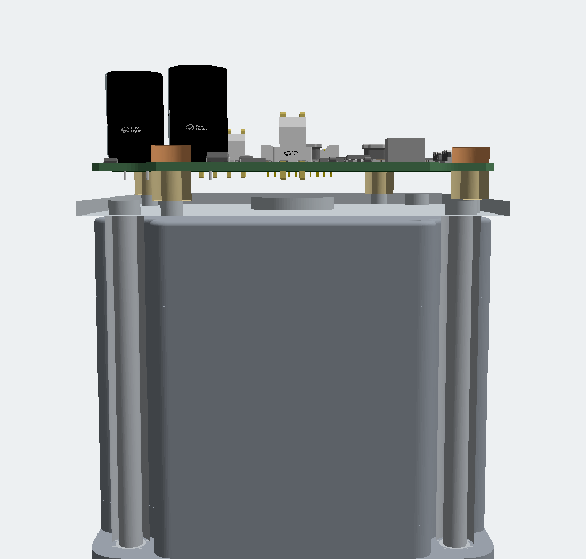
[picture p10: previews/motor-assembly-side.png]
Motor-to-board spacing, side view


The exported assembly is checked for the PCB/motor axis mapping and **10 mm nominal** rear-face-to-PCB-bottom gap. `release/34hs31-6004s1-assembly-proposal.zip` contains the same assembly as an offline GLB.

## PCB screw clearance

The earlier PCB clearance correction moved Q12, Q13, R97, C5, R2 and SW1 on top and repaired their affected copper. This motor-model update does not change the PCB, schematic, mounting-hole positions or routing.

The component-mesh screen uses an 8 mm maximum head/washer diameter and 3.5 mm height above the PCB, with at least 0.5 mm nominal component clearance. Latest exact results are in `motor-assembly-check.json`.

| Hole | Nearest fitted component | Nominal head clearance |
|---|---|---:|
| H1 | Q12 | 0.79 mm |
| H2 | C22 | 1.09 mm |
| H3 | R2 | 0.88 mm |
| H4 | SW1 | 1.38 mm |

These are imported CAD-body clearances, not a tolerance study. Use M4 hardware whose complete head and washer remain within Ø8 mm. A larger washer is outside this check. Assembly tolerances and tool access remain to be qualified.

## Proposed adapter

The drawing specifies four Ø6.5 mm front holes on a **69.6 ±0.2 mm square**. The STEP centers are `(±34.75, ±34.75)` mm, giving 69.5 mm pitch, within that tolerance. Front flange surfaces lie at STEP Z = 0 and 10 mm. The rear face lies at Z = 79.5 mm; the drawing permits an 80 mm maximum body. Four proposed supports run from the rear of the front flange to a separate plate behind the motor.

| Item | Nominal proposal |
|---|---|
| Support posts | Four, Ø8 mm × 70.5 mm; M5 fastening interfaces |
| Rear plate | 85.9 × 85.9 × 3 mm, 6061-T6 aluminum; Ø20 mm center aperture |
| Motor-to-plate gap | 1 mm at the CAD body length |
| PCB standoffs | Four, M4, Ø8 mm × 6 mm |
| PCB bottom above motor rear | 1 + 3 + 6 = **10 mm** nominal |
| PCB hole pattern carried by plate | H1 `(38.4,−24.5)`, H2 `(24.5,38.4)`, H3 `(−38.4,24.5)`, H4 `(−24.5,−38.4)` mm |
| Plate clearance holes | Ø5.5 mm at motor posts; Ø4.5 mm at PCB standoffs |

The mesh screen finds approximately **1.23 mm** minimum nominal clearance between the proposed long posts and the motor case. STEP X/Y map to PCB X/Y; STEP Z is the shaft axis. The motor rear face is placed at PCB Z = −10.8 mm; PCB mid-plane is Z = 0 and its bottom is Z = −0.8 mm. The shaft points away from the board. The board lies parallel to the motor rear face.

At the drawing's 80 mm maximum body length, the nominal 1 mm plate gap becomes 0.5 mm before any other tolerances. The full tolerance stack is unresolved. The posts also share the motor's **front machine-mounting interface**; this has not been approved for the intended machine. Bracket clearance, bolt engagement, post-end design, tolerances, tightening torque, stiffness/vibration, cable strain relief and heat transfer require mechanical review. The GLB shows nominal envelopes, not detailed threads or a qualified fastener kit.

## Encoder attachment unresolved

U18 remains on top, centered on the motor axis. The ordered motor STEP is a single fused mesh. It shows a rear central recess, but does not identify a rotating shaft end, usable pilot bore/thread or approved magnet attachment. A visible rear recess is not proof that a holder can be attached to the rotor.

The old QSH-specific pilot, PEEK holder, magnet dimensions and working-gap calculation are withdrawn. Manufacturer confirmation of rear rotating-shaft access is required before defining a new attachment. If there is no usable rear shaft, an alternative encoder coupling or motor variant must be agreed; the current preview does not resolve that choice.

Any eventual magnet must meet the AS5047P field, alignment and temperature requirements through the top-side sensor stack. Retention, runout and magnetic performance need qualification. Closed-loop operation remains unqualified.

## Before mechanical release

1. Approve use of the front machine-mount holes and finalize bracket/post fasteners, tolerances and cable access.
2. Establish rear rotating-shaft access and an appropriate encoder attachment, or agree an alternative arrangement.
3. Select and qualify the magnet/holder, field and working gap if magnetic feedback is retained.
4. Qualify physical fit, tool access, support strength, retention and vibration.

Motor identity is now confirmed. Driver current/hold settings, rotor/load inertia, speed and stopping duty remain unqualified. These mechanical and operating gates are additional to the existing PD-image, firmware and powered-test holds.

References: [ordered Amazon listing](https://www.amazon.com/dp/B091C83HWF), [manufacturer product](https://www.omc-stepperonline.com/s-series-nema-34-stepper-motor-4-8nm-679-87oz-in-14mm-key-way-shaft-1m-cable-34hs31-6004s1), [AS5047P datasheet](https://look.ams-osram.com/m/d05ee39221f9857/original/AS5047P-DS000324.pdf), [tscircuit subassembly](https://docs.tscircuit.com/elements/assembly-subassembly).

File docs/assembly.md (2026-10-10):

# PD1180-EPR — NEMA 34 Smart Motor-Mounted Stepper Controller with USB-C PD 3.1 EPR

## Assembly

The requested deliverable is a fabricated, fully populated, programmed and functionally tested PCBA. Ordering remains on hold. `bun run check:release` checks the documented release gates; it is not a powered test. Follow [the README startup procedure](../README.md#connections-and-operation) and [power-validation.md](power-validation.md) for commissioning.

### Stack and placement

- 85.9 × 85.9 mm, 1.6 mm, four-layer board with four 4.2 mm mounting holes and 1 oz copper on all layers. The fabricator must confirm the USB impedance stack-up; current/thermal qualification remains pending.
- Assembly is top-side only. All fitted components, the AS5047P, its local bypass parts and service pads are on top. The encoder is centered on the intended motor shaft. Magnet dimensions, air gap, alignment and stray-field effects are validated during mechanical bring-up.
- The ten CSD19534Q5A drain pads contain four connected 0.60/0.30 mm through vias each (40 total), and U34 has four exposed-pad thermal vias. The final top-side route has 69 via drills overlapping top solder lands; exact locations are recorded in `engineering/top-side-placement.json`. Order epoxy-filled and copper-capped processing for every via-in-pad, with no finished via drill below 0.30 mm.
- Check the imported land patterns, solder-mask/paste openings and manufacturer package drawings. JLC/EasyEDA data are a starting point, not a substitute for footprint review.
- Bulk capacitors and JST headers are through-hole; clarify hand/wave/selective assembly with the assembler. Check capacitor polarity and the 25 mm capacitor height.

### Connector pinout

| Connector | Pins in order |
|---|---|
| J1, PD POWER | Dedicated USB-C EPR power; 48 V / 5 A requested contract; no USB data |
| J10, USB DATA | USB 2.0 to STM32 and separate current-limited logic supply; no motor power |
| J2, motor | 1 A1, 2 A2, 3 B1, 4 B2 |
| J3, external brake | 1 VMOTOR, 2 switched resistor return (not a permanent ground) |
| J7, industrial harness | 1 HOME, 2 STOP L, 3 STOP R, 4 IN0, 5 IN1, 6 STEP, 7 DIR, 8 GND, 9 RS232 TX, 10 RS232 RX, 11 GND, 12 CAN H, 13 CAN L, 14 GND, 15 RS485 A, 16 RS485 B, 17 VMOTOR, 18 HW ENABLE, 19 OUT0, 20 OUT1 |

Pin numbering follows the imported physical footprints. J7 is the 20-pin B20B-PHDSS(LF)(SN), with PHDR-20VS mating housing. Its signal map is authoritative in `hardware-contract.json`. J7 pin 17 carries nominal 48 V VMOTOR, not regulated 24 V. J6/J9 are retired; do not use their old pinouts. Inputs remain nominal 24 V, with a shared ground. Mating housings, contacts, wire gauge and strain relief are separate procurement items.

## Programming and external items

Program U3 with the approved TI-generated TPS26750 full-flash image and U16 with board-specific firmware before motor bring-up. The TI image is currently missing; the supplied STM32 image is for motion-locked commissioning only. Keep POWER_PERMIT and MCU_RUN low in blank/reset/fault states. SWD is a 3.3 V interface provided on labelled top service pads; use a pogo fixture with the adjacent 3.3 V and ground pads.

### Programming and test work order

JLCPCB currently offers [programming](https://jlcpcb.com/help/article/pcba-programming-service) and [functional testing](https://jlcpcb.com/help/article/functional-test-service) for **Standard PCBA**, subject to review of the customer's files, interfaces and test method. Programming takes place after assembly. Request these services explicitly and obtain acceptance for this board's 48 V motor/brake test and fixture; no service has been booked or confirmed here.

Supply the following before approving a ready-to-run batch:

1. Exact board revision and release hashes; matching top BOM/CPL; complete through-hole/tall-part assembly scope; 69 filled/capped via-in-pad locations and the agreed stack-up.
2. U3 **M24512-RMN6TP**: approved full-flash BIN, hash, reviewed EEPROM programming method and readback verification. [TI's EVM guide](https://www.ti.com/lit/ug/slvucp8/slvucp8.pdf) describes generating the full-flash binary. This board's U3 uses EEP_SDA/EEP_SCL on U2's I2Cc bus, separate from the STM32's PD_SDA/PD_SCL host bus. Post-assembly access, power sequencing and bus ownership still need a demonstrated fixture method; do not assume SWD or J10 directly programs this EEPROM.
3. U16 **STM32G0B1CBT6**: qualified motor-enabled BIN/HEX, hash, SWD pad drawing, flash address `0x08000000` for a raw BIN, supply arrangement and readback procedure. The existing commissioning archive is suitable only for initial diagnostic testing. Do not substitute it as the final motor-operating image.
4. Exact motor and brake load, qualified current/microstep settings, STEP pulse/ direction timing and maximum rate, supply/cable, external 24 V controls, heatsink, enclosure and ambient limits. These operating limits must come from first-article qualification, not the 5.5 A target alone.
5. An accepted fixture and test procedure: labelled power/USB/motor/J7 connections, current limiting, probes, controlled loads, expected readings, stop criteria and an operator demonstration. Agree who performs first-article qualification and who tests the remaining boards.

### Request to send to the assembly/test provider

> Please quote fabrication, complete top-side assembly, programming and pre-shipment functional testing for PD1180-EPR r0.4. Include the through-hole headers/bulk capacitors and the specified filled/capped vias. Please confirm whether your team can commission a 48 V USB-PD EPR controller and qualify its external-MOSFET stepper stage with a supplied motor, brake resistor/heatsink and load fixture. The design target is 5.5 A RMS per phase; that is not yet a qualified operating rating. First-article engineering qualification must precede approval of the motor-enabled firmware and batch acceptance procedure. Each shipped assembly must have verified U3/U16 programming, a controlled STEP/DIR run in both directions and the agreed power/fault tests, with serial-numbered records. Do not ship a blank or motion-locked assembly as ready to run. Please identify the programming interfaces, fixture requirements, first-article test owner, cost and lead time before acceptance. The TI image and final operating envelope are still being prepared; the present package is for engineering review, not production authorization.

This request is prepared but has **not been sent or accepted**. Provider/contact, actual motor/load, maximum speed, stopping profile, supply/cable and brake cooling must be supplied before the work order can be completed.

### First-article programming sequence

1. Approve the exact release manifest and record the board serial. Keep J2 disconnected and hardware enable inactive. The assembly/test provider must approve the fixture's power arrangement; do not connect two independent sources to one supply rail.
2. Program the motion-locked STM32 commissioning image over SWD and verify it, following [firmware/README.md](../firmware/README.md). Capture `HELP`, `STATUS` and `DRIVER` responses; these are diagnostic evidence, not a motor test.
3. Program U3 with the **full-flash** binary generated for this board, verify its complete contents against that binary, then cold-start U2 and record its mode, identity, boot status and negotiated contract. Agree a direct-EEPROM fixture or preprogrammed-part method before assembly; isolate other bus drivers as required by the fixture design. Access on the assembled board is not yet demonstrated.
4. TI's [SLVAFL1 §2.1–2.2](https://www.ti.com/lit/an/slvafl1/slvafl1.pdf) distinguishes initial full-flash programming from later host updates. The `FLrd`/`FLad`/`FLwd`/`FLvy` update sequence assumes a working application and initialized EEPROM regions. It is not an established blank-board programming path here. Do not load a low-region update file at EEPROM address zero or assume the STM32 commissioning image implements those commands.
5. Complete the no-motor tests in [power-validation.md](power-validation.md), then have the qualification engineer produce and identify a controlled motor-test firmware build. Record every configuration change. Begin below 1 A RMS; increase current only after phase-current, gate and fault measurements pass. The existing commissioning image cannot execute this step.
6. After the agreed motor/load envelope passes, approve the exact motor-enabled image and per-board test revision. Program and verify that image on every shipped board, repeat the acceptance tests, and deliver its hashes and operating settings with the board. A failed test returns to engineering; it never becomes a pass by removing the test or suppressing a protection.

### Acceptance record

No hardware results exist yet. Complete first-article qualification using every applicable row in [power-validation.md](power-validation.md). From that qualified design, approve a repeatable per-board test covering:

| Per-board evidence | Acceptance requirement |
|---|---|
| Assembly inspection | Correct revision/parts, polarity, solder joints, filled/capped lands and all ordered through-hole parts fitted |
| Programming | U3/U16 identity, exact image hashes, successful verify/readback and reset behavior recorded |
| Power and USB | Required rails within qualified limits, negotiated 48 V / 5 A contract, no unintended enable, USB diagnostics and source transitions working |
| Motor operation | Controlled STEP/DIR test in both directions at the approved current/speed/load; record measured phase current and driver status |
| Inhibits and stop | Hardware enable, limits, watchdog/reset and the approved fault tests inhibit motion; no automatic re-arm |
| Thermal/brake | Test at the qualified load/duty/ambient using the approved resistor/heatsink; record bus peak and temperatures against approved limits |
| Handoff | Board serial, inspector/tester, date, instruments, results, firmware/configuration hashes and PASS/FAIL; retain supporting traces/video |

Blank devices, a programmed-but-motion-locked image, a USB-only demo, or an assembly photograph do not meet the requested ready-to-run acceptance. Keep shipment acceptance pending until the agreed tests pass; do not replace missing results with a CAD check. Factory testing against a qualified fixture also does not establish operation with an unspecified motor or load.

The EPR charger, EPR cable, motor, shaft magnet, external braking resistor/heatsink and bus terminators are not assembled PCB components. Their final part numbers and load-dependent ratings are release gates. All populated PCB parts have timestamped JLCSearch evidence; external-brake stock is still unverified.

The exact ordered STEPPERONLINE 34HS31-6004S1 CAD is available in `motor-assembly.circuit.tsx` through `assembly.subassembly`. Direct rear mounting and rotating-shaft access are not established. [Motor assembly](motor-assembly.md) records the proposed front-flange-supported adapter, 10 mm nominal motor-to-PCB gap, screw clearances and unresolved encoder attachment. Approve the shared front interface, tolerances and support strength before fabrication. The former QSH-specific magnet/holder proposal is withdrawn. Do not treat the PD86 mounting-template match as proof of fit to this motor.

## Imported-part corrections

The STM32 registry component is retained with a complete datasheet pin-label override, power/ground attributes and a courtyard. CSD19534 drain thermal vias are implemented in the final KiCad route with explicit drain-net identities and bottom copper ties. Q2/Q3 use the exact CSD17484F4 PicoStar-3 land pattern and G/S/D pin map from the imported JLC part. BAV21 polarity is explicit, bulk capacitor pads carry polarity aliases, imported transistor symbols have reference text, and vertical headers specify top-side cable insertion.

## PD power-path enable buffer

Fit Q2/Q3 as CSD17484F4 (`C2862245`), R9/R12 as 0 Ω (`C21189`), and R11/R13 as 100 kΩ (`C25803`). Both pull-ups terminate at `PD_3V3`, U2's LDO_3V3 rail. This is the two-NMOS non-inverting buffer in the TPS26750 EVM and Figure 8-5 of the TPS26750 datasheet. R10 is intentionally absent; do not add the retired BJT base pull-down.

## Logic backup supply

U22, L2 and U24 provide motor-side logic backup; U5, L1 and U23 provide PD-side startup. Fit both LM66100 parts and R111. The wiring follows TI Figure 17: U23 CE senses V3V3_MOTOR, U23 ST and U24 CE share LOGIC_OR_PRIORITY, and R111 pulls that interlock up to V3V3_PD. U24 ST is grounded because it is unused. U26/U27 separately combine board V3V3 and DATA-derived V3V3_USB into V3V3_MCU. Do not substitute the simpler common-output CE wiring; equal inputs can turn both devices off. The 3.3 V service pads are logic references; an external accessory current budget has not been allocated.

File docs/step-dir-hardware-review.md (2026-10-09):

# External STEP/DIR hardware blocker — 2026-10-09

Status: **r0.4 ECO source and routed-board correction verified; powered validation pending**.
The user reopened architecture scope on 2026-10-09. U7 pins23/24 now connect to GND and pin25 is NC; encoder SPI and ABI service pads remain. The original finding below describes the r0.3 baseline.

The user selected external STEP/DIR with USB setup/diagnostics. The original r0.3 U7 TMC5160A wiring sent AS5047P encoder B/A/I to U7 pins 23/24/25. The ADI TMC5160A Rev. 1.18 datasheet, page 13, specifies different functions when SD_MODE=1 and SPI_MODE=1:

| U7 pin | Original r0.3 net | STEP/DIR function | Consequence |
|---|---|---|---|
| 23 | ENC_B from U18 pin 6 | DCEN input | Encoder transitions can enable dcStep unexpectedly. ADI says ground or leave open for ordinary STEP/DIR. |
| 24 | ENC_A from U18 pin 7 | DCIN input | Encoder transitions enter the dcStep gating input. |
| 25 | ENC_I from U18 pin 14 | DCO output | Connected to the encoder's index output: output-to-output connection in this mode. |

Setting VDCMIN=0 does not prove safety: the datasheet explicitly describes the external DCEN input in STEP/DIR mode. No manufacturer-supported setting that makes all three existing connections safe has been validated. The commissioning firmware retains SD_MODE=0 and MCU_RUN=0 until the corrected hardware is verified on the bench.

## Correction implemented in ECO source

For the selected external STEP/DIR operating mode:

1. Disconnect U7 pins 23, 24 and 25 from ENC_B, ENC_A and ENC_I respectively.
2. Connect U7 pins 23 and 24 to GND; mark pin 25 unused/no-connect.
3. Preserve U18 and its SPI connections to U16, and preserve encoder test pads. USB diagnostics can read shaft angle through SPI.
4. Preserve the existing STEP/DIR multiplexers and signal paths. This proposal sacrifices direct TMC hardware ABI counting; it does not claim closed-loop position control.
5. Regenerate/reroute affected PCB nets and manufacturing files; require native DRC/ERC, exact endpoint-net matching and a new routing fingerprint derived from the changed circuit.

The user-authorized architecture ECO includes this connectivity correction. Unrelated schematic layout remains preserved. A dual-mode hardware design preserving direct ABI counting needs mode-controlled isolation instead, and is a larger ECO.

Primary sources:
- [ADI TMC5160A Rev. 1.18, pin functions page 13 and dcStep section 17.6](https://www.analog.com/media/en/technical-documentation/data-sheets/tmc5160a_datasheet_rev1.18.pdf)
- [ams OSRAM AS5047P manufacturer documentation](https://ams-osram.com/products/sensors/position-sensors/ams-as5047p-high-speed-position-sensor)
- Current authoritative `index.circuit.tsx`: U7 and U18 physical numbered-pin connections.

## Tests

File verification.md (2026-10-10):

# PD1180-EPR verification

Validated **2026-10-10T22:30:42.370Z** against the pinned local toolchain. This summary is generated by `bun run verify`; machine-readable results remain in [docs/verification.json](docs/verification.json).

| Check | Result | Time | Evidence |
|---|---:|---:|---|
| toolchain | PASS | 0.0 s | `docs/checks/toolchain.log` |
| cloud-package | PASS | 0.1 s | `docs/checks/cloud-package.log` |
| mounting-template | PASS | 2.5 s | `docs/checks/mounting-template.log` |
| typecheck | PASS | 12.3 s | `docs/checks/typecheck.log` |
| import-previews | PASS | 1.5 s | `docs/checks/import-previews.log` |
| firmware-pins | PASS | 0.0 s | `docs/checks/firmware-pins.log` |
| firmware | PASS | 3.7 s | `docs/checks/firmware.log` |
| firmware-target | PASS | 0.1 s | `docs/checks/firmware-target.log` |
| operating-mode | PASS | 0.0 s | `docs/checks/operating-mode.log` |
| preview | PASS | 85.2 s | `docs/checks/preview.log` |
| source-schematic | PASS | 0.1 s | `docs/checks/source-schematic.log` |
| schematic-style | PASS | 0.8 s | `docs/checks/schematic-style.log` |
| feature-parity | PASS | 0.0 s | `docs/checks/feature-parity.log` |
| normalize-svgs | PASS | 0.1 s | `docs/checks/normalize-svgs.log` |
| script-catalog | PASS | 0.0 s | `docs/checks/script-catalog.log` |
| topology-tests | PASS | 146.6 s | `docs/checks/topology-tests.log` |
| netlist | PASS | 37.6 s | `docs/checks/netlist.log` |
| power-audit | PASS | 0.1 s | `docs/checks/power-audit.log` |
| schematic | PASS | 2.5 s | `docs/checks/schematic.log` |
| placement | PASS | 50.7 s | `docs/checks/placement.log` |
| routing-difficulty | PASS | 50.3 s | `docs/checks/routing-difficulty.log` |
| decoupling | PASS | 0.1 s | `docs/checks/decoupling.log` |
| assembly | PASS | 0.1 s | `docs/checks/assembly.log` |
| board-standards | PASS | 0.1 s | `docs/checks/board-standards.log` |
| local-copper | PASS | 2.2 s | `docs/checks/local-copper.log` |
| shorts | PASS | 11.4 s | `docs/checks/shorts.log` |
| kicad-drc | PASS | 0.0 s | `docs/checks/kicad-drc.log` |
| critical-copper | PASS | 0.1 s | `docs/checks/critical-copper.log` |
| usb-reference | PASS | 0.0 s | `docs/checks/usb-reference.log` |
| power-routing | PASS | 0.1 s | `docs/checks/power-routing.log` |
| routing-fingerprint | PASS | 0.1 s | `docs/checks/routing-fingerprint.log` |
| input-stability | PASS | 0.0 s | `docs/checks/input-stability.log` |

- Routed KiCad board verified: **yes**
- Prototype fabrication orderable: **no**
- Production released: **no**
- Verified entry SHA-256: `7b08d01f23d4bd1bed5919d8d0cd7eb7fb5912e787b642f3c0e4f12873159434`

Production remains gated by the TI PD image, STM32 target firmware, brake/load sizing, magnet alignment and powered thermal/EMC validation. See [docs/release-status.json](docs/release-status.json).

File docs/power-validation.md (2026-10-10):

# Power validation and prototype order review

**Status: power ECO CAD verified; order hold remains. No PCB has been assembled or powered.** The user authorized changes to the driver-supply and brake/OVP sections and removal of C19 from IMON on 2026-10-10. Unrelated schematic placement and symbols remain frozen. The regenerated native board has zero DRC violations, unconnected items, schematic-parity issues and ERC violations. Use only the matching regenerated manufacturing package; this CAD result does not close the system-validation gates.

## Independent pre-order audit — 2026-10-10

The audited native PCB SHA-256 is `c9007161c6b74a6dc9713a2e786b1761b4a3b42090f70075ccfa8724ed1677fb`, after the authorized C19 correction on base commit `b38aa63c568504deec009184d52fd277ab1c7e7c`. A fresh KiCad invocation, independent of the cached check reports, found zero DRC violations, unconnected items, schematic-parity issues and ERC violations. Raw reports: [PCB](checks/pre-order-native-drc.json), [schematic](checks/pre-order-native-erc.json). The complete automated review is recorded in [verification.json](verification.json); its passing results do not cover every manufacturer design instruction.

| Review area | Finding |
|---|---|
| Assembly and geometry | 294 fitted parts plus 11 service pads on top; minimum via drill 0.30 mm; 69 filled/capped via-in-pad locations |
| Local routing | All 46 specified bypass paths, nine Kelvin/analog branches, USB reference and power-routing checks passed |
| Filled-copper calculation | Re-exported the current native copper and solved MOTOR_A1 Q7:9 → R115:1 at 0.075/0.05 mm mesh: 3.2831/3.2946 mΩ, 0.349% difference; fine-mesh loss 0.0997 W at 5.5 A, excluding contacts/devices and thermal feedback. [Evidence](../engineering/filled-copper-review.json) |
| Driver initialization | Fixed reliance on OTP short-detection and dead-time defaults. Explicit register writes, disabled-chopper sequencing and write-corruption regressions pass. The regression failed on the previous configuration. See [firmware details](../firmware/README.md#tmc5160-external-stepdir-service) |
| TPS26631 current monitor | **Corrected:** removed C19 from source and native PCB; R26 and the ADC connection remain. The compiled-connectivity regression rejects an IMON-to-ground capacitor even after reference/net renaming. TI §8.3.9 prohibits this bypass because it delays current information; this is separate from the internal current limit. |
| Programming and operation | The TPS26750 full-flash image and qualified motor-operation firmware are absent. The supplied STM32 image supports commissioning diagnostics and deliberately keeps motion locked. The ordered motor is now identified as 34HS31-6004S1; approved current settings, load, stop profile and adapter/cable qualification remain open. |

The C19 correction removes only that component. Native footprint and route comparison verifies the remaining pads and existing tracks/vias are unchanged; matching schematic, BOM/CPL and manufacturing files are regenerated. See the `c19_correction` entry in [native placement evidence](../engineering/top-side-placement.json). The source connection was checked against [TI TPS2663 §8.3.9](https://www.ti.com/lit/ds/symlink/tps2663.pdf); generic CAD connectivity checks alone did not detect this component-specific rule.

**Disposition: keep the order hold.** Passing connectivity and design calculations does not mean the delivered assembly can currently run a motor. Programming and agreed functional acceptance must be completed before shipment for a ready-to-run delivery; provider acceptance and actual test records are not yet available. See [assembly requirements](assembly.md) and [order settings](../release/order-settings.json).

## Correction and calculation record

The original connection put U7 VSA on a motor bus whose brake threshold exceeded VSA's 50 V recommended operating limit. U34 now generates a separate 12 V rail from VMOTOR; U7 VSA and 12VOUT, including C61, connect to that rail. VS remains on VMOTOR. The compiled connectivity check rejects a short between these rails, including a short introduced by an explicit bypass trace. The external-supply range is 10–13 V; absolute maximum ratings are not used as operating limits. See [TMC5160A §3.2 and §28](https://www.analog.com/media/en/technical-documentation/data-sheets/tmc5160a_datasheet_rev1.18.pdf).

| Change | Design basis | Remaining qualification |
|---|---|---|
| U34 LMR36510ADDAR, L3 47 µH, R121 100 kΩ / R122 9.09 kΩ | Nominal 12.001 V; screened 11.57–12.57 V including resistor temperature and PFM allowances | Startup, ripple, bus collapse and driver/brake load steps |
| L3 SRP7050TA-470M | 37.6 µH at −20% versus approximately 23.1 µH minimum; 2.7 A saturation rating at 25 °C versus 2.4 A maximum high-side current limit | Hot saturation, loss and temperature rise |
| C86/C87 input; C88 VCC; C89 bootstrap; C90–C92 output | 2.2 µF + 220 nF / 100 V input; 1 µF VCC; 100 nF bootstrap; 3 × 22 µF / 25 V output | Effective capacitance under bias/temperature, switch-loop waveform and return paths |
| C32–C35 470 nF / 50 V X7R | MOSFET maximum gate charge is 22 nC; ADI recommends 470 nF above 20 nC. These capacitors see floating gate-drive differential voltage, not the full bus | Bootstrap droop, gate overshoot, dead time and minimum off-time |
| U12 REF3425, C93/C94; remove R59 | 2.5 V precision reference, with input/output bypassing; replaces shunt reference and bias resistor | Reference startup and operation during loss of either USB input |
| R60/R61 = 180 kΩ + 16 kΩ; R62 = 10 kΩ; R63 = 1 MΩ | Brake nominal on 51.99 V / off 51.34 V | Measured hysteresis, comparator offset/noise and switching overshoot |
| R64 = 430 kΩ; R65/R66 = 20 kΩ + 1 kΩ | Motor inhibit nominal 53.69 V; tolerance envelope must stay below 55 V with allocated transient margin | Dynamic shutdown response and regenerated energy after inhibit |
| R22 = 4.7 kΩ; R23 = 422 kΩ; R24 = 10 kΩ | eFuse input OVP nominal 52.40 V; screened 50.93–53.89 V, retaining margin above a 5% high 48 V source | Source tolerance, eFuse input leakage and PD transient coordination |

Reference data: [TI LMR36510 tables 8-1/8-4](https://www.ti.com/lit/ds/symlink/lmr36510.pdf), [Bourns SRP7050TA](https://www.bourns.com/docs/product-datasheets/srp7050ta.pdf), [REF34](https://www.ti.com/lit/ds/symlink/ref34.pdf), [TLV3201](https://www.ti.com/lit/ds/symlink/tlv3201.pdf), [TPS2663](https://www.ti.com/lit/ds/symlink/tps2663.pdf), and [CSD19534Q5A](https://www.ti.com/lit/ds/symlink/csd19534q5a.pdf).

`bun run check:power-audit` calculates the actual fitted-value envelopes and writes [the machine-readable report](../engineering/power-audit.json). The report hashes its source inputs. Its screening result does not assert that the hashed native PCB implements the new source: routing fingerprint, parity, DRC, local-copper and power-routing checks are separate mandatory gates. The 2 mV comparator noise/hysteresis and 0.5 V dynamic overshoot allowances are engineering allocations requiring measurement. Capacitor bias, switching losses, parasitics and thermal boundary conditions are not simulated.

C87 has a documented 3.3 mm pad-center placement limit: VIN is the second pin in U34's PowerPAD package, and the adjacent 0805 capacitor must clear the PGND land and package courtyard. Actual separation is approximately 3.166 mm, with a constrained top-layer path under 5 mm. All other bypass targets retain the 3 mm placement limit. This is not an exception to copper clearance, connectivity or the short ground-return requirement. L3 uses the manufacturer's recommended land pattern; its 3D object is a dimensioned body envelope, not a manufacturer STEP model.

The final native PCB has 294 fitted parts and 11 service pads on top, a minimum 0.30 mm finished via drill, 40 MOSFET drain thermal vias and four U34 exposed-pad thermal vias. The drill-over-solder-land audit counts **69 via-in-pad locations**, all requiring the selected filled/capped process. Exact coordinates and the board hash are in `engineering/top-side-placement.json`; order settings carry the same count. Native routing checks verify all 46 specified IC-to-capacitor top-layer paths within 5 mm, all nine Kelvin/analog-return branches, USB reference continuity and the power-corridor policy. The native bypass regression rejects the earlier copper with five missing or excessive paths.

## What the power numbers establish

At the 5.5 A RMS design target the sinusoidal phase peak is 7.78 A. The configured scaler nominally commands about 5.386 A RMS; that calculation is not a calibrated phase-current measurement. A 33 mΩ sense resistor has a conservative cycle-average bound of 1.00 W and a held-peak bound of 2.00 W. The eight bridge MOSFETs have approximately 1.83 W total conduction loss using maximum 25 °C on-resistance; doubling resistance gives 3.65 W. Neither number includes switching loss or predicts junction temperature.

The eFuse limit is about 4.48 A nominal at the input, not a phase-current limit. The screened upper limit leaves only about 0.14 A from a 5 A PD contract for upstream logic. TPS26631 also permits overload pulses. Source/cable negotiation, logic consumption and overload behavior must be tested together.

The 940 µF bank stores about 1.08 J at 48 V but accepts only about 0.237 J between 48 V and 53 V. A nominal 10 Ω brake dissipates about 270 W at turn-on; 55 V across a −2% resistor would dissipate 309 W. The selected [Vishay LPS300](https://www.vishay.com/docs/50052/lps300.pdf) is rated 300 W only with its case at or below 85 °C. It needs a designed heatsink and a verified pulse-energy/repetition budget. The ordered motor’s rotor inertia is not specified, so no rotor kinetic-energy result is available. Driven-load inertia and gravity must also be included.

## Evidence required before submitting a prototype order

- Fresh source build, electrical tests, schematic checks and native PCB/schematic parity; zero DRC violations and unconnected items.
- Top-only fitted BOM/CPL, local bypasses, preserved Kelvin paths, four-layer stack, at least 0.30 mm finished via drills, drain thermal vias and uninterrupted USB reference evidence.
- Fresh Gerber/drill ZIP and matching BOM/CPL, with SHA-256 provenance. Reject older ZIPs and manually substituted files.
- Exact stock/package checks for the actual order quantity, plus manufacturer confirmation of filled/capped via-in-pad processing and the chosen impedance stack-up.
- Review of the ordered 34HS31-6004S1 current waveform, supply/cable, maximum speed, stop time, rotor/load inertia, ambient temperature, enclosure and brake heatsink. These operating details remain unqualified.
- A documented PD programming path. `docs/pd-configuration.json` contains requirements only; the TI-generated full-flash image is still missing. Do not substitute that JSON for an EEPROM binary.

## Staged powered test record — all results pending

Use a current-limited bench setup, rated differential probes, a current probe/electronic load and temperature sensors. Attach the brake resistor and load only after their ratings and wiring are checked. Keep motor enable inactive until supply and fault tests pass. Save oscilloscope traces, instrument ranges/calibration, ambient temperature, firmware/configuration hashes and board serial number for each row.

| Stage | Exercise | Acceptance / stop criterion | Result |
|---|---|---|---|
| Unpowered | Assembly, resistance, polarity, QFN/drain joints, shorts, filled vias and harness pinout | No assembly defect; explain each unexpectedly low resistance before power | Not tested |
| 5 V logic | J1 and J10 independently and together; blank EEPROM, erased MCU, SWD and USB | Correct logic rails; VMOTOR and bridge stay disabled with invalid firmware/configuration | Not tested |
| PD and handover | Approved TI image; attach/detach, hard reset, EPR cable, source swaps, USB suspend/resume | 48 V / 5 A contract proven; USB/PD ratings respected; no backfeed or unintended motor enable | Not tested |
| eFuse | No-motor load sweep, startup/inrush, UVLO, OVP, overload and fault recovery | Measured thresholds inside the report's screen; valid source coordination; no SOA or temperature violation | Not tested |
| Driver supply | U34 output at U7 and U15, startup, brake pulses, supply removal and load steps | VSA/12VOUT remain 10–13 V while operating; no destructive overshoot or unwanted gates; capture ripple | Not tested |
| Reference and brake | Controlled bus ramp with rated brake load; both directions and temperature corners | Brake acts before inhibit; VS always below 55 V, including transient allowance; resistor case ≤85 °C | Not tested |
| Inhibit matrix | External enable open/grounded, MCU reset/watchdog, PGOOD loss, overvoltage and overtemperature | Bridge disables for every fault; no automatic restart without the intended permit sequence | Not tested |
| Low-current motor | Start below rated phase current; inspect all bridge VGS/VDS and current waveforms | Correct phase/polarity; no shoot-through; bootstrap/gate limits respected before increasing current | Not tested |
| Rated-current soak | Increase current in stages, then standstill and loaded motion at worst intended ambient | Measured RMS/peak current and all derated component/motor temperatures acceptable; document thermal equilibrium | Not tested |
| Regeneration | Defined load, speed, stop time and repeated stops, including USB loss | Bus remains within limits; brake pulse/average energy and temperatures pass; no uncontrolled movement | Not tested |
| Interfaces and compliance | USB during switching, STEP/DIR rate, industrial buses, cable faults, magnetic alignment, ESD/EMC | Meets the intended system requirements and applicable test limits; record failures | Not tested |

Full-power operation is established only after these measurements on assembled hardware. A passing design calculation or CAD report cannot close the powered, thermal or EMC gates.

## Qualification work sheet for the provider

Complete and approve this envelope **before** a motor-enabled test. Empty fields mean the qualification is not ready to execute; the design target is not an acceptance value.

| Required input | Agreed value |
|---|---|
| Provider, responsible engineer and first-article serial | Not supplied |
| Motor manufacturer/model, phase wiring and driver current | STEPPERONLINE 34HS31-6004S1; A+ black, A− green, B+ red, B− blue. Manufacturer rating 6 A/phase; approved RMS/hold setting pending |
| Driven load, inertia/gravity, maximum RPM and acceleration | Not supplied |
| Worst stop/deceleration profile and repeat interval | Not supplied |
| J1 source model and EPR cable model/rating | Not supplied |
| Brake resistor, heatsink, mounting and airflow | Not qualified |
| Ambient range, enclosure, duty cycle and thermal limits | Not agreed |
| Microsteps, current settings and STEP/DIR timing limits | Not qualified |
| TI configuration/full-flash hashes and motor-test firmware hash | Not available |
| Fixture revision, instrument list and calibration dates | Not supplied |

For every matrix row, retain: board/release identity; procedure revision; operator/date; actual motor/load/ambient; instrument setup; programmed settings; numeric expected limits and their source; readings with units; waveform/photo/log filenames; PASS/FAIL; and the engineer's disposition. A record labelled “not tested” is not acceptable shipment evidence.

First-article qualification covers operating corners and fault behavior. The provider must then approve a repeatable production acceptance procedure and duration. Every shipped board needs its own programming verification and both-direction motor/fault record; a single prototype video does not accept the batch. Neither that production procedure nor any powered result has been approved yet. See the [prepared provider request and programming sequence](assembly.md#request-to-send-to-the-assemblytest-provider).

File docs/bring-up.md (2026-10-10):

# PD1180-EPR — NEMA 34 Smart Motor-Mounted Stepper Controller with USB-C PD 3.1 EPR

## Bring-up plan

Use the [power validation matrix](power-validation.md) for the approved power ECO, numeric limits, required evidence and pending test results. No powered tests have been performed.

Complete routing, design review and assembly inspection before these steps. Use current-limited equipment and a PD protocol analyzer; do not begin with an unrestricted 48 V source and motor attached.

1. Inspect supply-to-ground resistance, polarity, QFN solder joints, filled vias, connector pin numbering and shunt Kelvin paths. Leave hardware enable open.
2. Connect J1 PD POWER at default 5 V, then connect J10 USB DATA. Verify 3.3 V, PD LDO rails, crystal startup, SWD and USB enumeration. VMOTOR must remain off with an erased MCU and blank/invalid PD EEPROM.
3. Program the TI-generated sink-only image. Confirm 5 V bootstrap, EPR cable identification, 48 V/5 A contract, GPIO2 EPR signaling, TPD fault handling and rejection of source/VCONN role swaps. Probe VBUS_LV through the SPR→EPR transition; it must stay within the PD controller's recommended range.
4. With an electronic load in place of the motor, verify eFuse UVLO, OVP, current-limit tolerance, inrush slew, fault latch/reset and reverse blocking. Test detach, hard reset and 3.3 V collapse while EPR VBUS is present. Check that bulk-capacitor energy cannot feed the USB port.
5. Connect the qualified external brake resistor. Use a controlled source to raise VMOTOR and measure brake turn-on, turn-off, switching overshoot, thermal rise and independent voltage shutdown. Size pulse energy and average power for rotor plus driven load; disconnect/hard-reset cases are required.
6. With no motion commanded, verify DRV_EN_N for every combination of MCU_RUN, motor power-good, voltage-good and external enable. Open enable, grounded enable, MCU reset and watchdog timeout must all disable the bridge.
7. Begin at low phase current with the actual motor. Verify high/low-side VGS, dead time, absence of shoot-through and correct shunt polarity. Increase current only after current regulation and temperatures are measured. Characterize 5.5 A RMS as a target, not a guaranteed rating.
8. Verify encoder magnetic field, alignment, counts, SPI framing and direction. Confirm stop/home polarities, input thresholds and Step/Dir frequency limits. Exercise both ramp and external Step/Dir modes.
9. Test RS232, CAN and RS485 with correct external termination/bias. Confirm USB operation while the motor switches, then perform applicable ESD/EMC and cable-fault tests.

Record waveforms, measured component temperatures, firmware/configuration hashes and pass/fail limits. Update `release-status.json` only after the associated evidence exists.

### Logic backup and USB loss

With the motor disconnected, supply VMOTOR from a current-limited bench supply and disconnect both USB cables. Confirm U22 maintains V3V3, U13/U14 and the brake reference operate, PD_VBUS and USB_DATA_VBUS stay unpowered, and the bridge enable returns inactive. Sweep both buck inputs and load V3V3 through the expected range; scope handover droop and reverse current through U23/U24. Exercise the brake at progressively higher bus voltage with a rated load and verify current, hysteresis, switch stress and worst-case comparator/reference tolerances before attempting regenerative motor tests.

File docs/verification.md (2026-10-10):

# Verification evidence

The current generated summary is [verification.md](../verification.md), with per-check results and input hashes in [verification.json](verification.json). Run `bun run review` to refresh engineering checks, live supplier evidence and review artifacts.

Native manufacturing evidence is in `dist/manufacturing/kicad-drc.json` and `dist/manufacturing/kicad-erc.json`. The checks include all severities, connectivity and schematic parity. The current route record is [routing-report.json](routing-report.json), and the final terminal-only sense-path evidence is [critical-copper-check.json](critical-copper-check.json).

`check:release` additionally enforces [release-status.json](release-status.json). Passing CAD checks does not clear the order hold: USB power behavior, clipped power-copper necks, thermal performance, TI configuration and powered commissioning remain unqualified. Production and motor operation are not released.

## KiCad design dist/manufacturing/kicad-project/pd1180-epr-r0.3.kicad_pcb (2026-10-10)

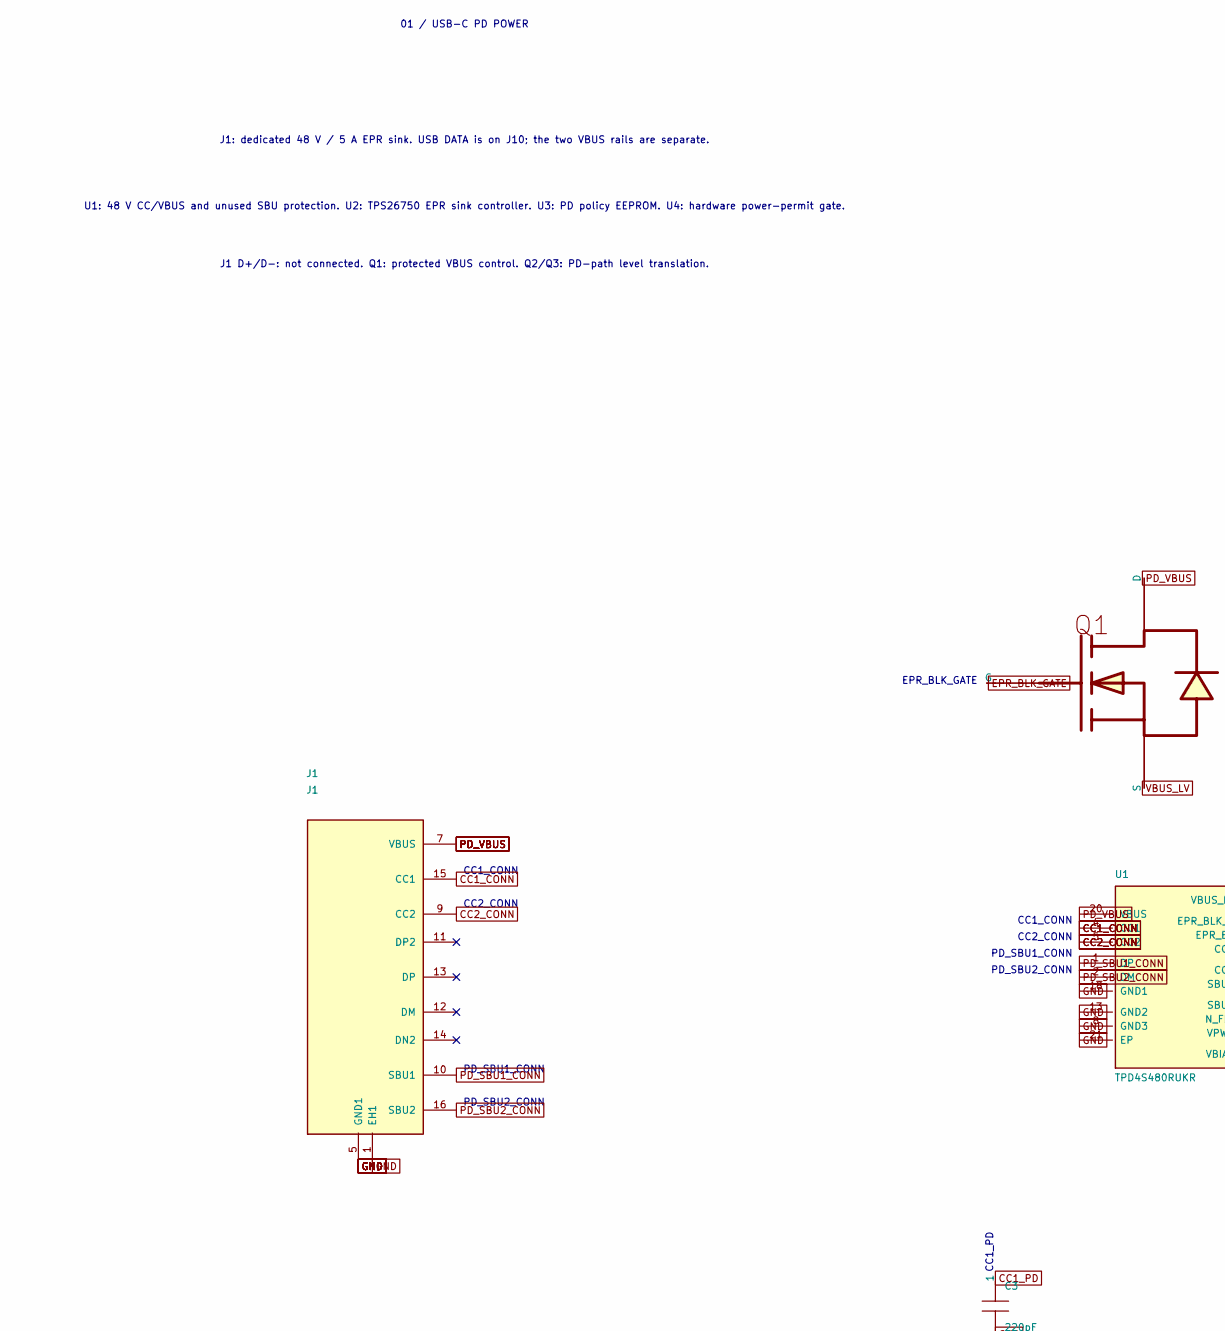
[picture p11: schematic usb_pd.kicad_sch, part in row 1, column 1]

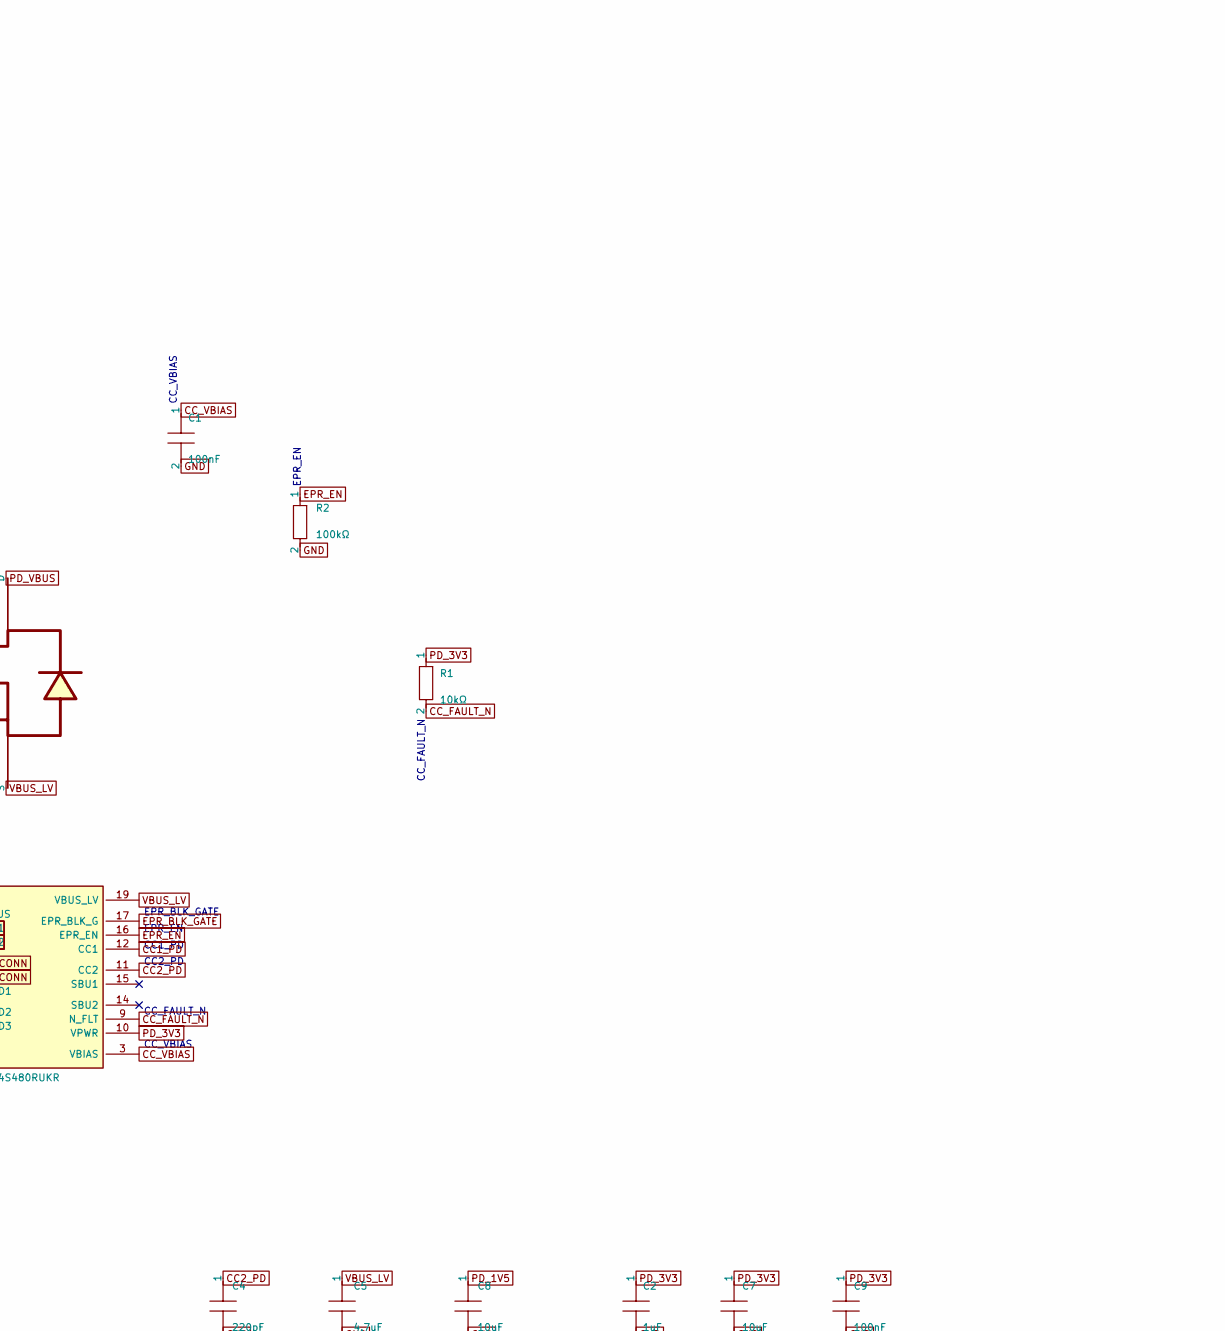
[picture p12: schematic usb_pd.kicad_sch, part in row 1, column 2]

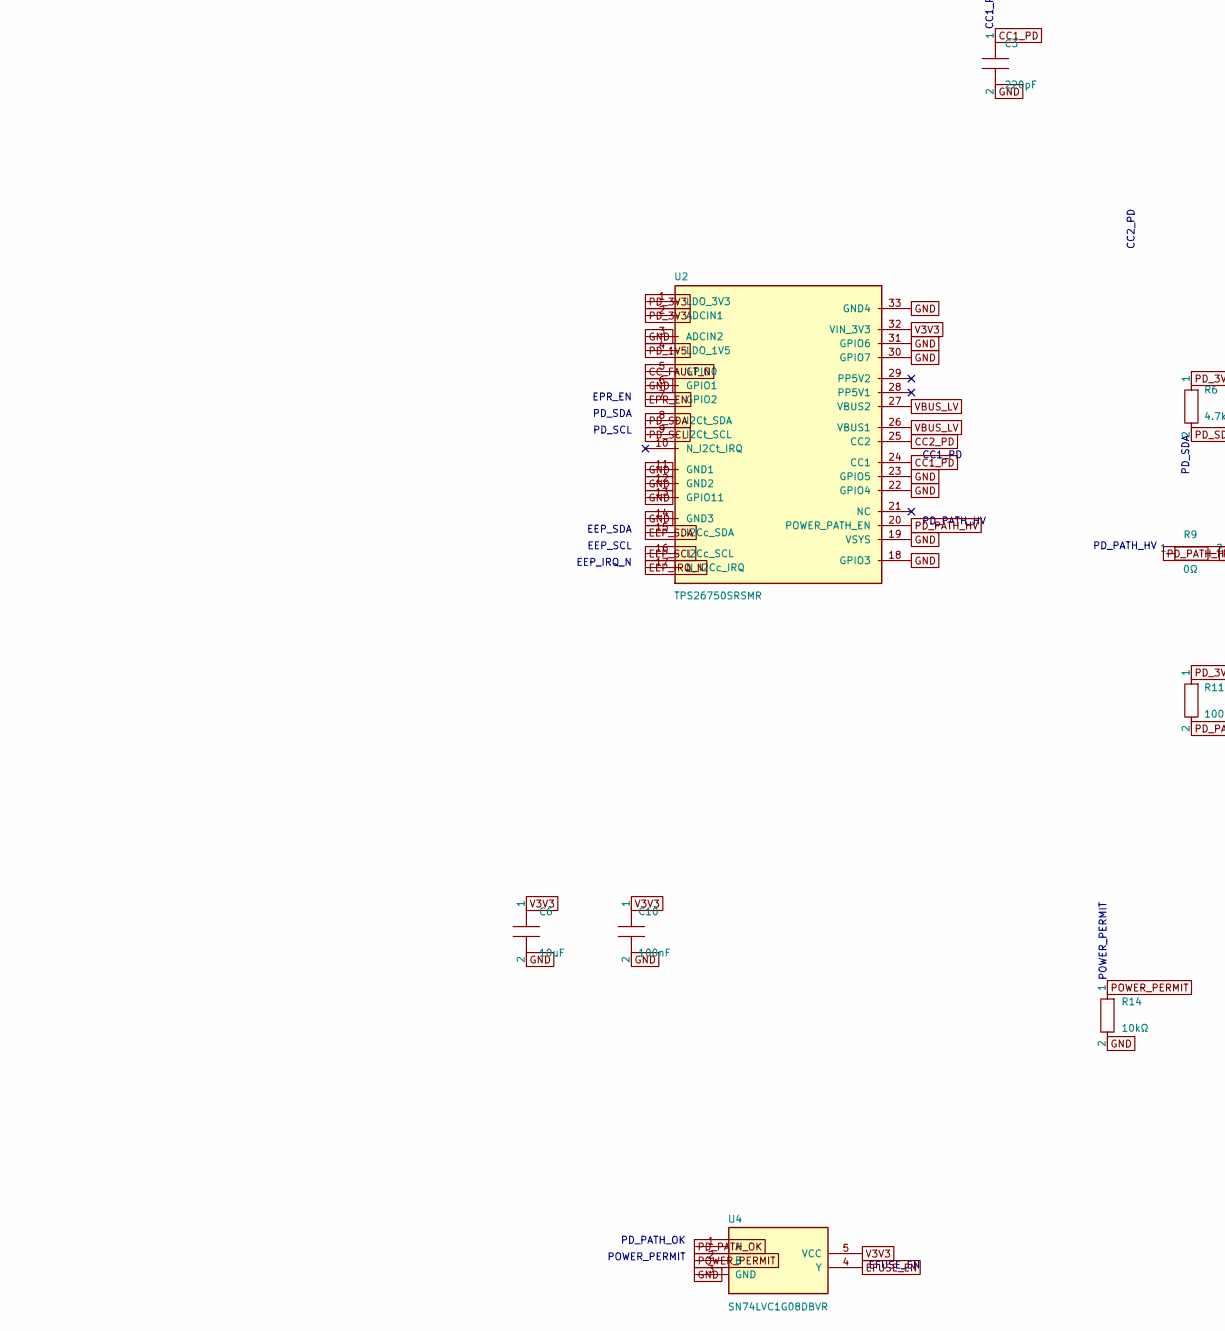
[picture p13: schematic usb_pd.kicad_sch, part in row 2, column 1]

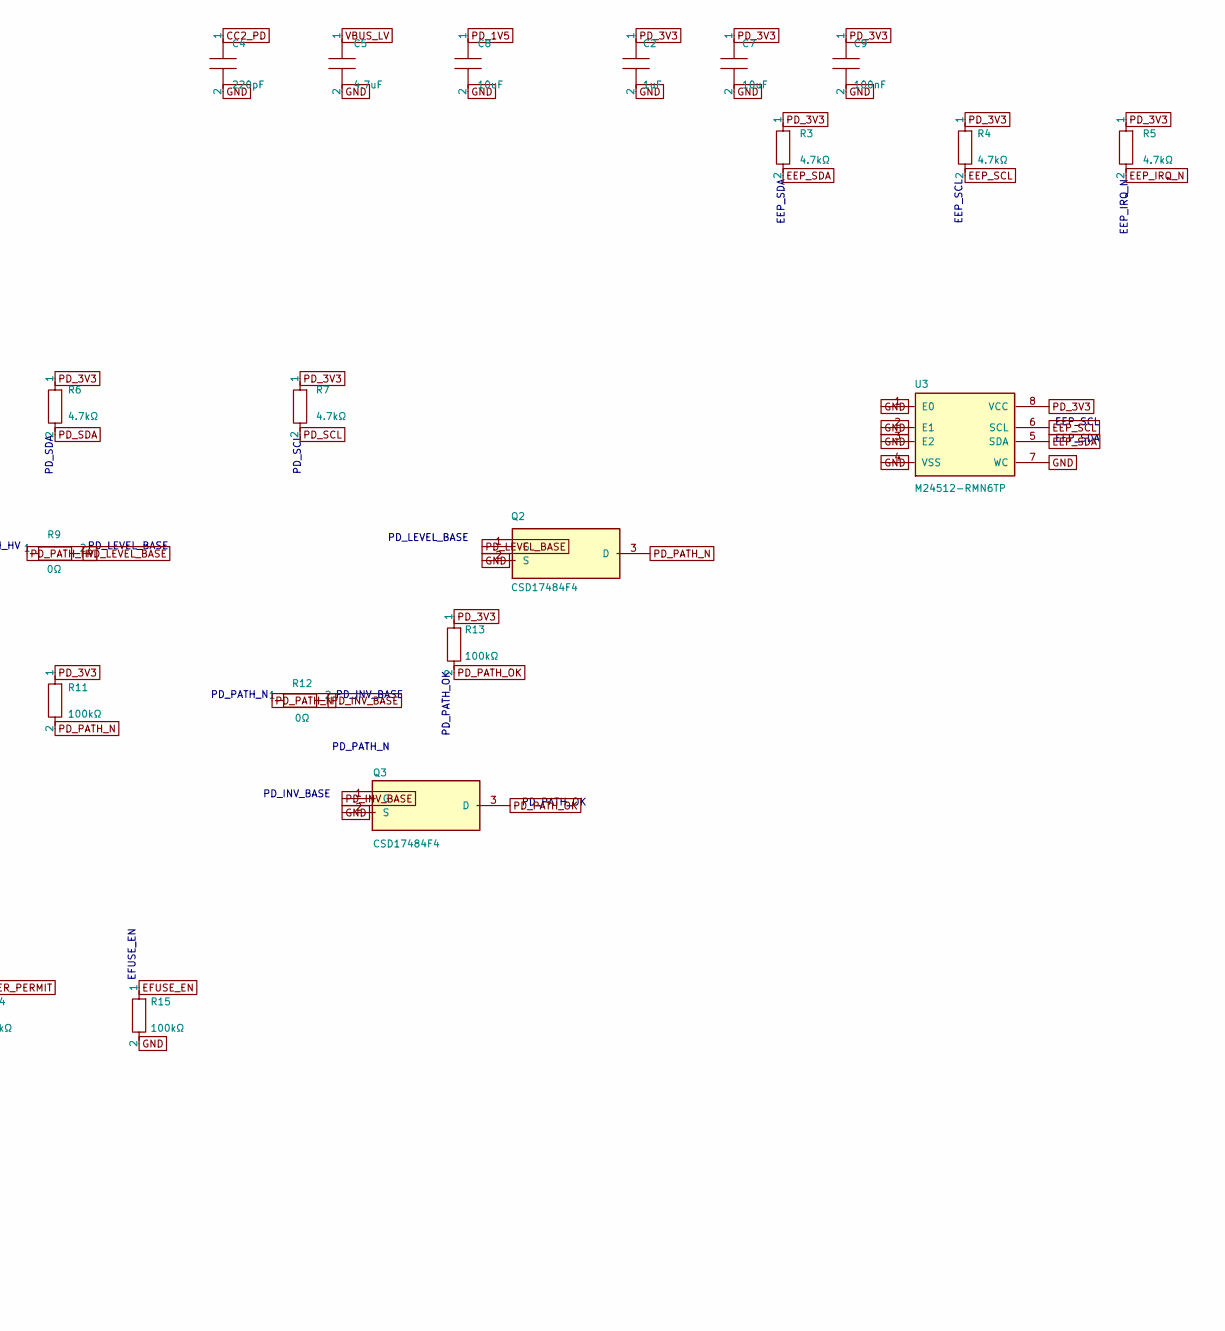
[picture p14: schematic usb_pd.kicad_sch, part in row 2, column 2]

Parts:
C1, C9, C10: 100nF; capacitor_cap0603
C2: 1uF; capacitor_cap0603
C3, C4: 220pF; capacitor_cap0603
C5: 4.7uF; capacitor_cap1206
C6, C7, C8: 10uF; capacitor_cap0603
J1: J1; USB4105-GF-A
Q1: Q1; BSS123LT1G
Q2, Q3: CSD17484F4
R1, R14: 10kΩ; resistor_res0603
R2, R11, R13, R15: 100kΩ; resistor_res0603
R3, R4, R5, R6, R7: 4.7kΩ; resistor_res0603
R9, R12: 0Ω; resistor_res0603
U1: TPD4S480RUKR
U2: TPS26750SRSMR
U3: M24512-RMN6TP
U4: SN74LVC1G08DBVR

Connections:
CC1_CONN: J1.15 (CC1), U1.4 (CC1), U1.7 (CC1)
CC1_PD: C3.1, U1.12 (CC1), U2.24 (CC1)
CC2_CONN: J1.9 (CC2), U1.5 (CC2), U1.6 (CC2)
CC2_PD: C4.1, U1.11 (CC2), U2.25 (CC2)
CC_FAULT_N: R1.2, U1.9 (N_FLT), U2.5 (GPIO0)
CC_VBIAS: C1.1, U1.3 (VBIAS)
EEP_IRQ_N: R5.2, U2.17 (N_I2Cc_IRQ)
EEP_SCL: R4.2, U2.16 (I2Cc_SCL), U3.6 (SCL)
EEP_SDA: R3.2, U2.15 (I2Cc_SDA), U3.5 (SDA)
EFUSE_EN: R15.1, U4.4 (Y); also elsewhere on the board
EPR_BLK_GATE: Q1.1 (G), U1.17 (EPR_BLK_G)
EPR_EN: R2.1, U1.16 (EPR_EN), U2.7 (GPIO2)
GND: C1.2, C2.2, C3.2, C4.2, C5.2, C6.2, C7.2, C8.2, C9.2, C10.2, J1.1 (EH1), J1.2 (GND1), J1.3 (GND1), J1.4 (GND1), J1.5 (GND1), J1.6 (GND1), J1.19 (GND1), J1.20 (GND1), Q2.2 (S), Q3.2 (S), R2.2, R14.2, R15.2, U1.8 (GND3), U1.13 (GND2), U1.18 (GND1), U1.21 (EP), U2.3 (ADCIN2), U2.6 (GPIO1), U2.11 (GND1), U2.12 (GND2), U2.13 (GPIO11), U2.14 (GND3), U2.18 (GPIO3), U2.19 (VSYS), U2.22 (GPIO4), U2.23 (GPIO5), U2.30 (GPIO7), U2.31 (GPIO6), U2.33 (GND4), U3.1 (E0), U3.2 (E1), U3.3 (E2), U3.4 (VSS), U3.7 (WC), U4.3 (GND); also elsewhere on the board
PD_1V5: C8.1, U2.4 (LDO_1V5)
PD_3V3: C2.1, C7.1, C9.1, R1.1, R3.1, R4.1, R5.1, R6.1, R7.1, R11.1, R13.1, U1.10 (VPWR), U2.1 (LDO_3V3), U2.2 (ADCIN1), U3.8 (VCC)
PD_INV_BASE: Q3.1 (G), R12.2
PD_LEVEL_BASE: Q2.1 (G), R9.2
PD_PATH_HV: R9.1, U2.20 (POWER_PATH_EN)
PD_PATH_N: Q2.3 (D), R11.2, R12.1
PD_PATH_OK: Q3.3 (D), R13.2, U4.1 (A)
PD_SBU1_CONN: J1.10 (SBU1), U1.1 (DP)
PD_SBU2_CONN: J1.16 (SBU2), U1.2 (DM)
PD_SCL: R7.2, U2.9 (I2Ct_SCL); also elsewhere on the board
PD_SDA: R6.2, U2.8 (I2Ct_SDA); also elsewhere on the board
PD_VBUS: J1.7 (VBUS), J1.8 (VBUS), J1.17 (VBUS), J1.18 (VBUS), Q1.3 (D), U1.20 (VBUS); also elsewhere on the board
POWER_PERMIT: R14.1, U4.2 (B); also elsewhere on the board
V3V3: C6.1, C10.1, U2.32 (VIN_3V3), U4.5 (VCC); also elsewhere on the board
VBUS_LV: C5.1, Q1.2 (S), U1.19 (VBUS_LV), U2.26 (VBUS1), U2.27 (VBUS2)

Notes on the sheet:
01 / USB-C PD POWER
J1: dedicated 48 V / 5 A EPR sink. USB DATA is on J10; the two VBUS rails are separate.
U1: 48 V CC/VBUS and unused SBU protection. U2: TPS26750 EPR sink controller. U3: PD policy EEPROM. U4: hardware power-permit gate.
J1 D+/D-: not connected. Q1: protected VBUS control. Q2/Q3: PD-path level translation.
CC2_CONN
PD_SBU1_CONN
CC1_CONN
PD_SBU2_CONN
CC_VBIAS
CC_FAULT_N
CC2_PD
CC1_PD
EPR_EN
EEP_SDA
EEP_SCL
PD_PATH_N
PD_PATH_OK
EPR_BLK_GATE
PD_SDA
PD_SCL
EEP_IRQ_N
PD_PATH_HV
PD_LEVEL_BASE
PD_INV_BASE
POWER_PERMIT
EFUSE_EN

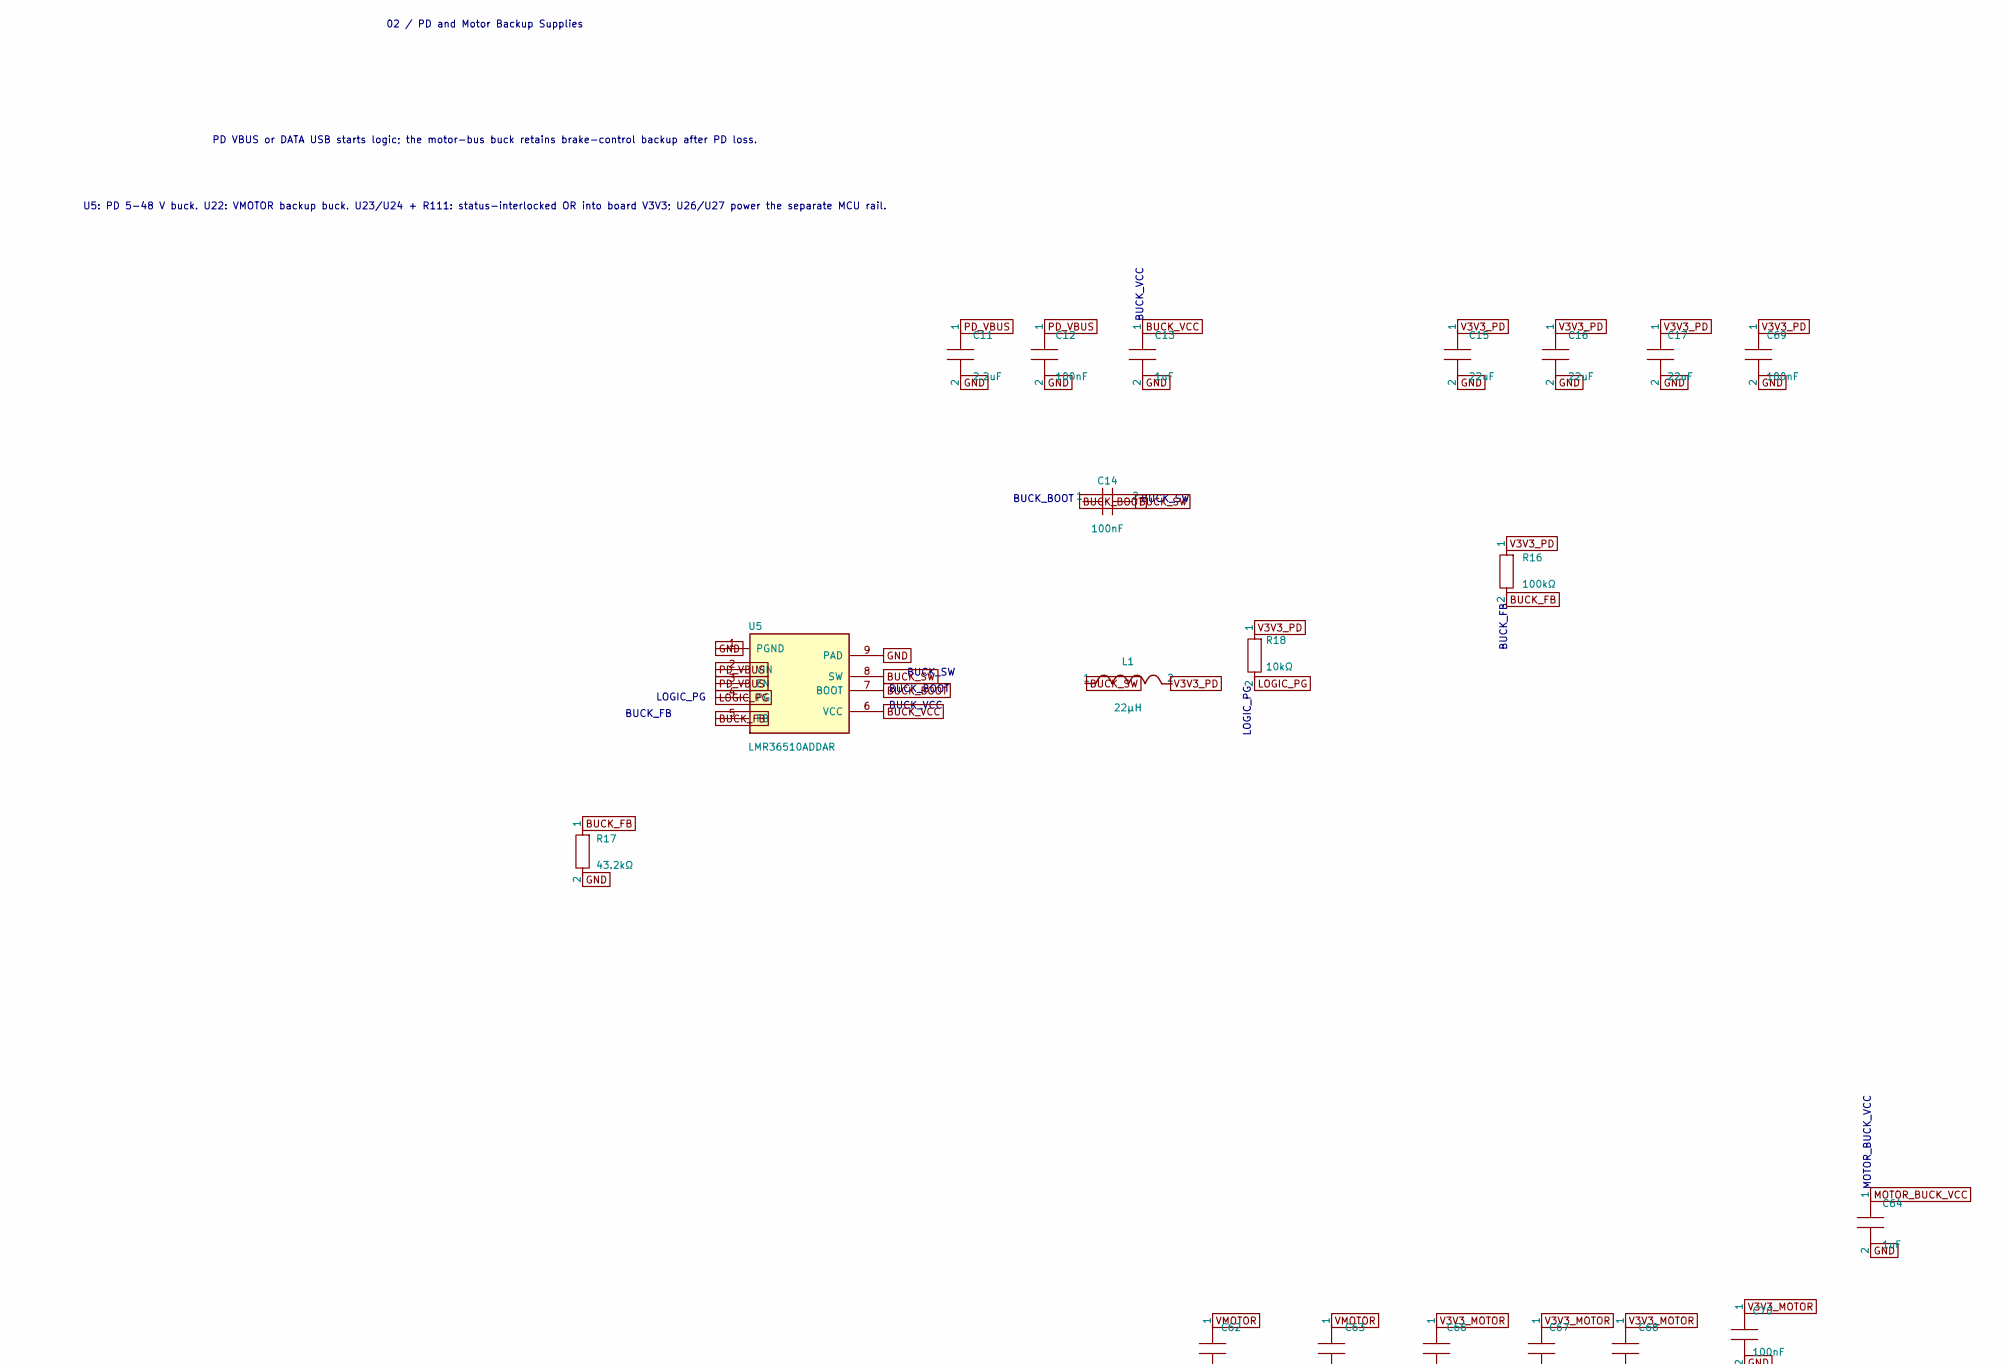
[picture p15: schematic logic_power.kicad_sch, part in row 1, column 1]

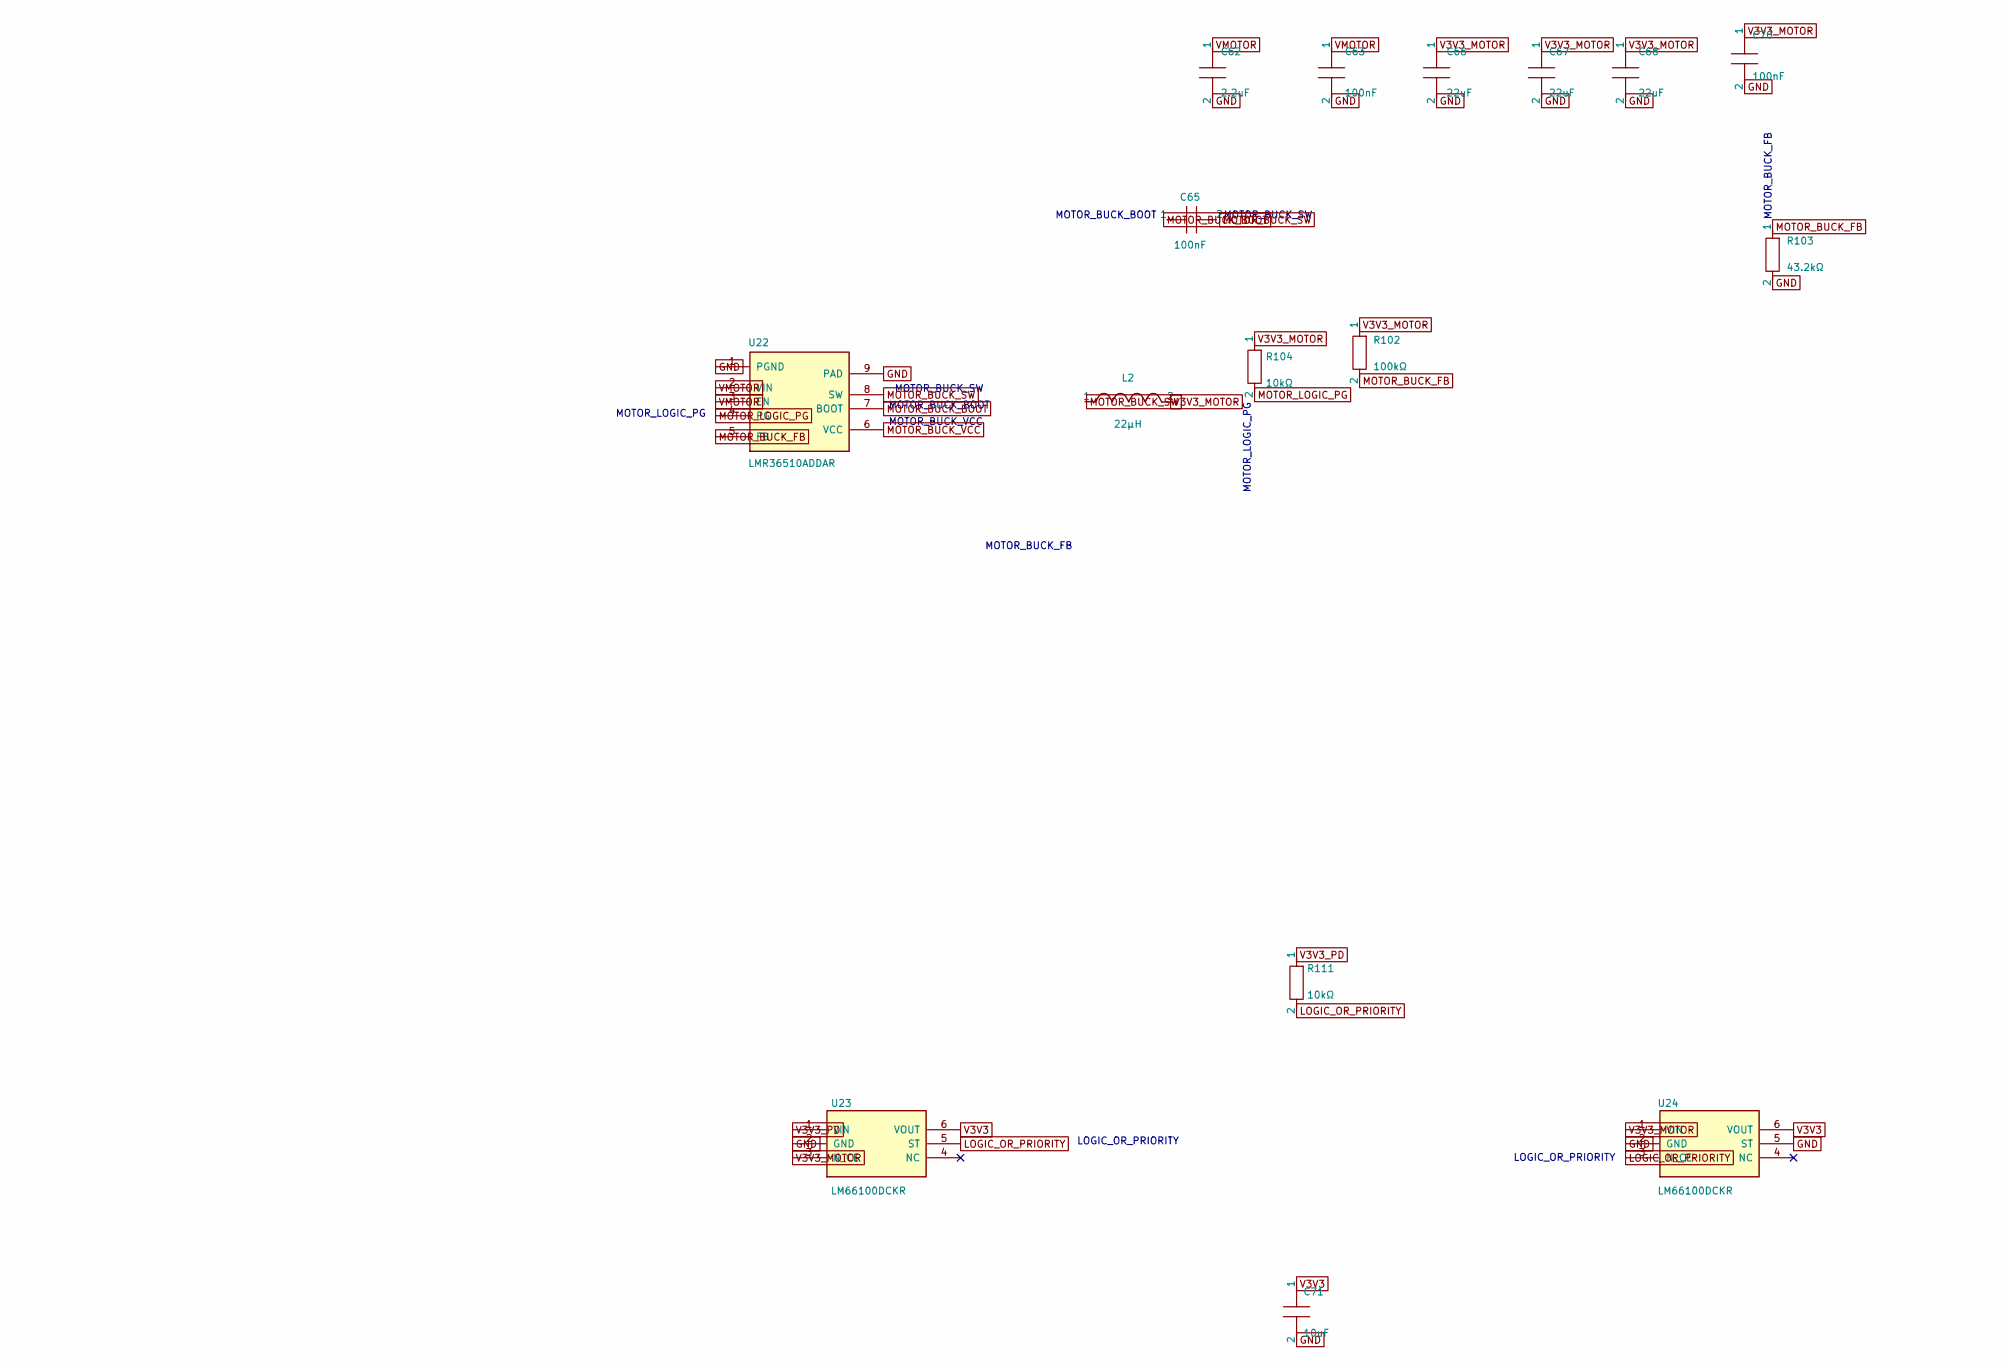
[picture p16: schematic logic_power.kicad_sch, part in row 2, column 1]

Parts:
C11, C62: 2.2uF; capacitor_cap1206
C12, C14, C63, C65, C69, C70: 100nF; capacitor_cap0603
C13, C64: 1uF; capacitor_cap0603
C15, C16, C17, C66, C67, C68: 22uF; capacitor_cap0805
C71: 10uF; capacitor_cap0603
L1, L2: 22µH; SWPA6045S220MT
R16, R102: 100kΩ; resistor_res0603
R17, R103: 43.2kΩ; resistor_res0603
R18, R104, R111: 10kΩ; resistor_res0603
U5, U22: LMR36510ADDAR
U23, U24: LM66100DCKR

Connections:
BUCK_BOOT: C14.1, U5.7 (BOOT)
BUCK_FB: R16.2, R17.1, U5.5 (FB)
BUCK_SW: C14.2, L1.1, U5.8 (SW)
BUCK_VCC: C13.1, U5.6 (VCC)
GND: C11.2, C12.2, C13.2, C15.2, C16.2, C17.2, C62.2, C63.2, C64.2, C66.2, C67.2, C68.2, C69.2, C70.2, C71.2, R17.2, R103.2, U5.1 (PGND), U5.9 (PAD), U22.1 (PGND), U22.9 (PAD), U23.2 (GND), U24.2 (GND), U24.5 (ST); also elsewhere on the board
LOGIC_OR_PRIORITY: R111.2, U23.5 (ST), U24.3 (N_CE)
LOGIC_PG: R18.2, U5.4 (PG)
MOTOR_BUCK_BOOT: C65.1, U22.7 (BOOT)
MOTOR_BUCK_FB: R102.2, R103.1, U22.5 (FB)
MOTOR_BUCK_SW: C65.2, L2.1, U22.8 (SW)
MOTOR_BUCK_VCC: C64.1, U22.6 (VCC)
MOTOR_LOGIC_PG: R104.2, U22.4 (PG)
PD_VBUS: C11.1, C12.1, U5.2 (VIN), U5.3 (EN); also elsewhere on the board
V3V3: C71.1, U23.6 (VOUT), U24.6 (VOUT); also elsewhere on the board
V3V3_MOTOR: C66.1, C67.1, C68.1, C70.1, L2.2, R102.1, R104.1, U23.3 (N_CE), U24.1 (VIN)
V3V3_PD: C15.1, C16.1, C17.1, C69.1, L1.2, R16.1, R18.1, R111.1, U23.1 (VIN)
VMOTOR: C62.1, C63.1, U22.2 (VIN), U22.3 (EN); also elsewhere on the board

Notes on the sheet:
02 / PD and Motor Backup Supplies
PD VBUS or DATA USB starts logic; the motor-bus buck retains brake-control backup after PD loss.
U5: PD 5-48 V buck. U22: VMOTOR backup buck. U23/U24 + R111: status-interlocked OR into board V3V3; U26/U27 power the separate MCU rail.
LOGIC_PG
BUCK_FB
BUCK_SW
MOTOR_BUCK_FB
MOTOR_BUCK_SW
LOGIC_OR_PRIORITY
BUCK_VCC
BUCK_BOOT
MOTOR_LOGIC_PG
MOTOR_BUCK_VCC
MOTOR_BUCK_BOOT

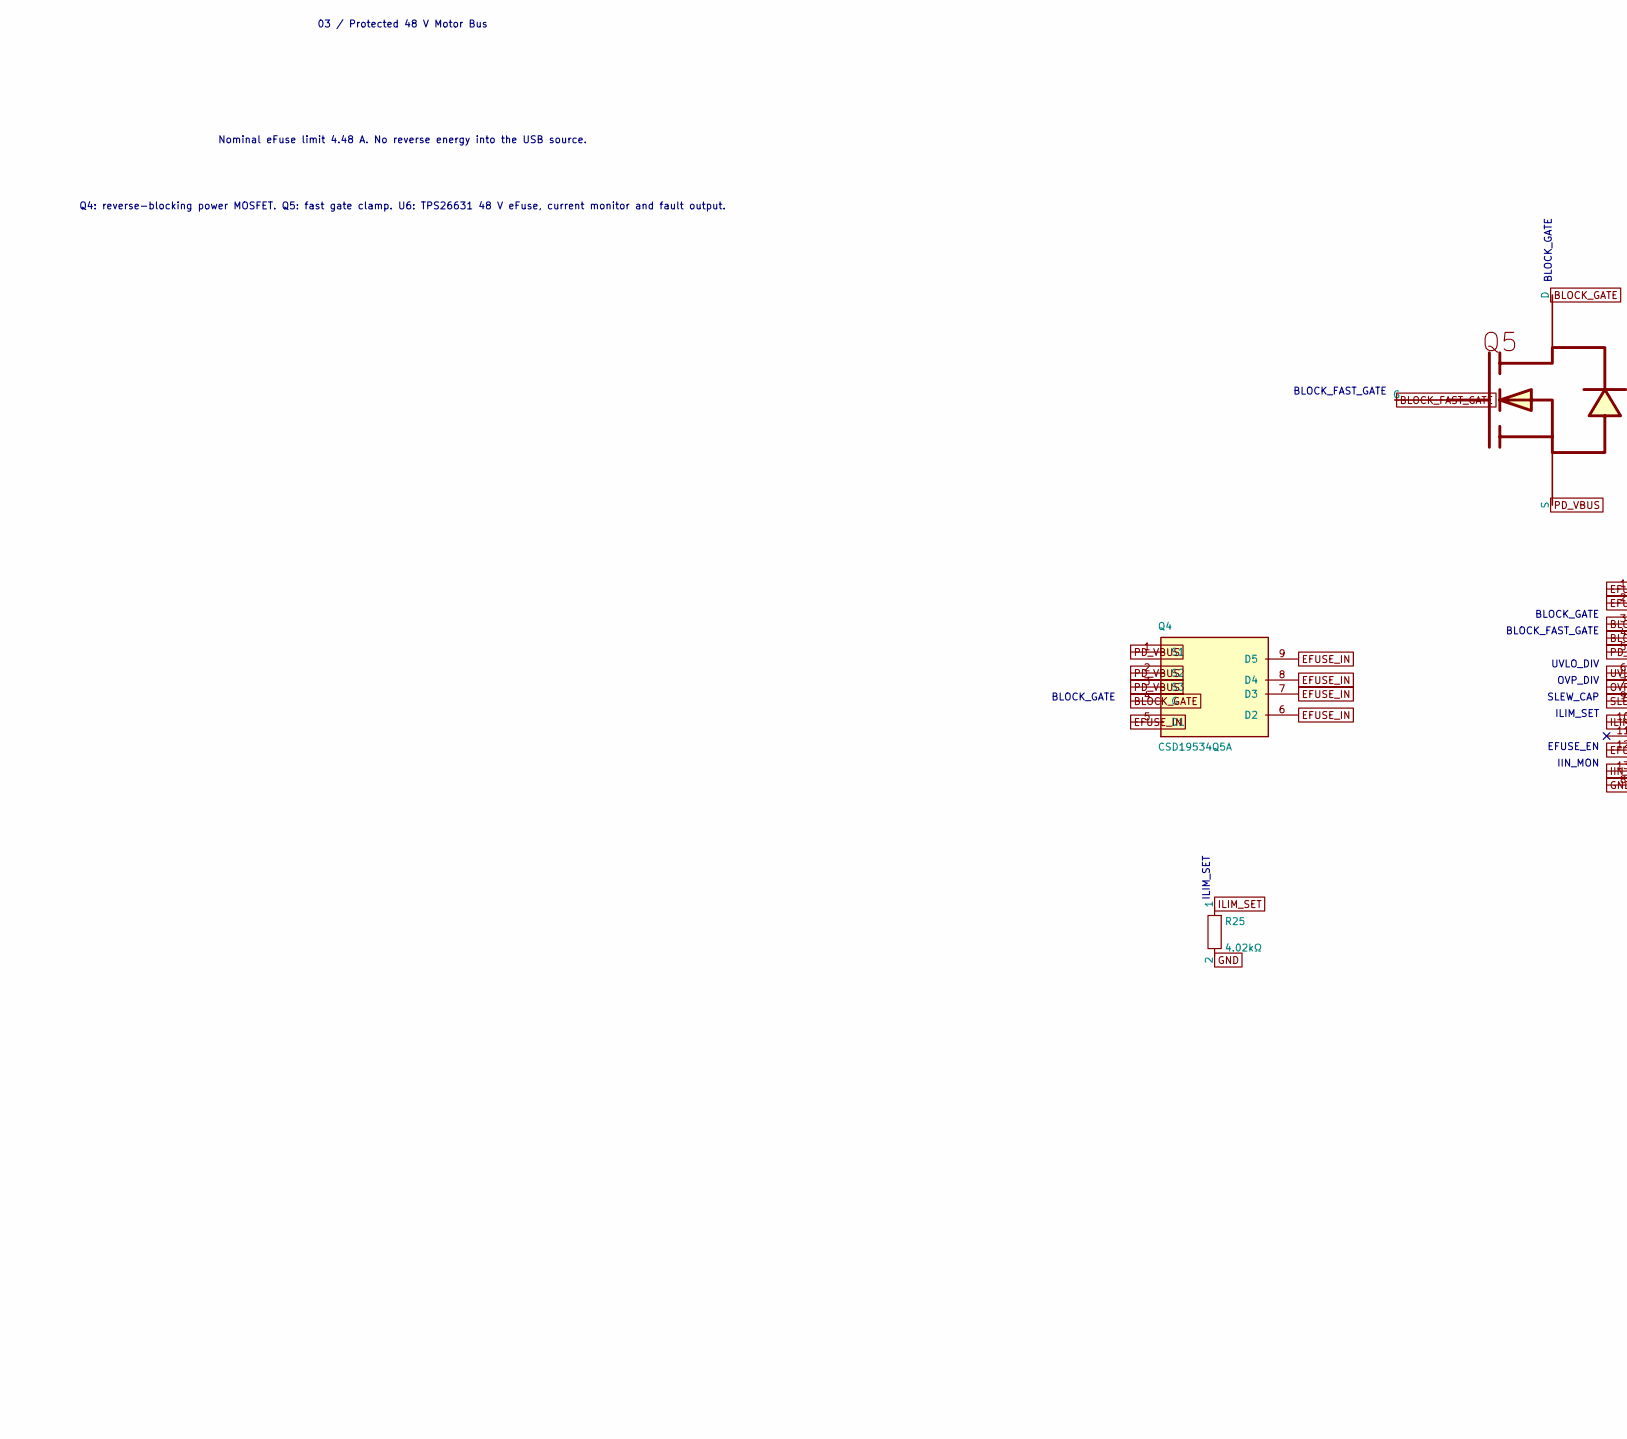
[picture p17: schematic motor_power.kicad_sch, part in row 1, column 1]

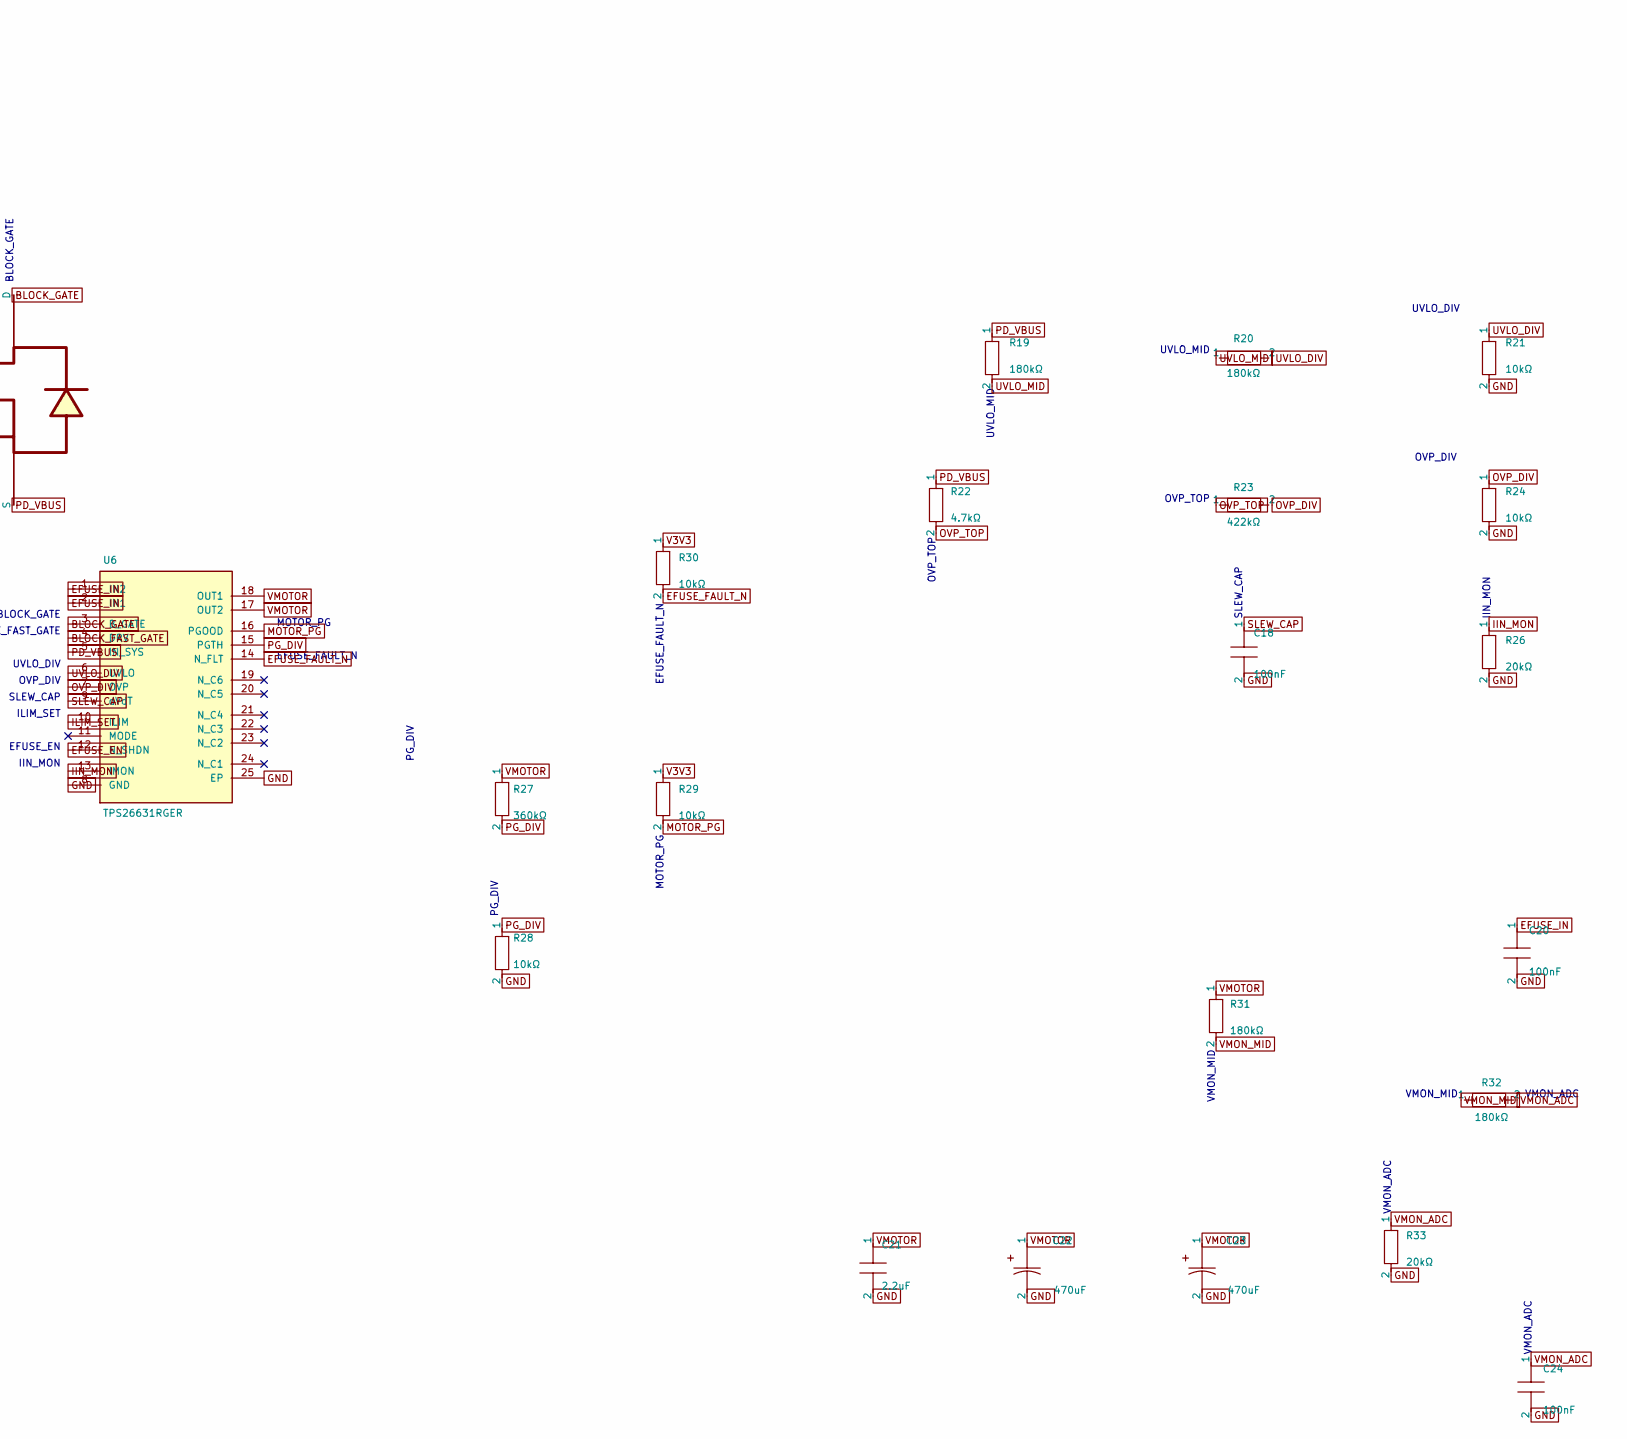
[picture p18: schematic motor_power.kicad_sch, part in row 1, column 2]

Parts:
C18, C20, C24: 100nF; capacitor_cap0603
C21: 2.2uF; capacitor_cap1206
C22, C23: 470uF; EEUFR1J471
Q4: CSD19534Q5A
Q5: Q5; BSS123LT1G
R19, R20, R31, R32: 180kΩ; resistor_res0603
R21, R24, R28, R29, R30: 10kΩ; resistor_res0603
R22: 4.7kΩ; resistor_res0603
R23: 422kΩ; resistor_res0603
R25: 4.02kΩ; resistor_res0603
R26, R33: 20kΩ; resistor_res0603
R27: 360kΩ; resistor_res0603
U6: TPS26631RGER

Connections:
BLOCK_FAST_GATE: Q5.1 (G), U6.4 (DRV)
BLOCK_GATE: Q4.4 (G), Q5.3 (D), U6.3 (B_GATE)
EFUSE_EN: U6.12 (N_SHDN); also elsewhere on the board
EFUSE_FAULT_N: R30.2, U6.14 (N_FLT); also elsewhere on the board
EFUSE_IN: C20.1, Q4.5 (D1), Q4.6 (D2), Q4.7 (D3), Q4.8 (D4), Q4.9 (D5), U6.1 (IN2), U6.2 (IN1)
GND: C18.2, C20.2, C21.2, C22.2, C23.2, C24.2, R21.2, R24.2, R25.2, R26.2, R28.2, R33.2, U6.8 (GND), U6.25 (EP); also elsewhere on the board
IIN_MON: R26.1, U6.13 (IMON); also elsewhere on the board
ILIM_SET: R25.1, U6.10 (ILIM)
MOTOR_PG: R29.2, U6.16 (PGOOD); also elsewhere on the board
OVP_DIV: R23.2, R24.1, U6.7 (OVP)
OVP_TOP: R22.2, R23.1
PD_VBUS: Q4.1 (S1), Q4.2 (S2), Q4.3 (S3), Q5.2 (S), R19.1, R22.1, U6.5 (IN_SYS); also elsewhere on the board
PG_DIV: R27.2, R28.1, U6.15 (PGTH)
SLEW_CAP: C18.1, U6.9 (dVdT)
UVLO_DIV: R20.2, R21.1, U6.6 (UVLO)
UVLO_MID: R19.2, R20.1
V3V3: R29.1, R30.1; also elsewhere on the board
VMON_ADC: C24.1, R32.2, R33.1; also elsewhere on the board
VMON_MID: R31.2, R32.1
VMOTOR: C21.1, C22.1, C23.1, R27.1, R31.1, U6.17 (OUT2), U6.18 (OUT1); also elsewhere on the board

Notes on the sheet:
03 / Protected 48 V Motor Bus
Nominal eFuse limit 4.48 A. No reverse energy into the USB source.
Q4: reverse-blocking power MOSFET. Q5: fast gate clamp. U6: TPS26631 48 V eFuse, current monitor and fault output.
BLOCK_GATE
UVLO_DIV
OVP_DIV
PG_DIV
VMON_ADC
BLOCK_FAST_GATE
SLEW_CAP
ILIM_SET
EFUSE_EN
IIN_MON
EFUSE_FAULT_N
MOTOR_PG
UVLO_MID
OVP_TOP
VMON_MID

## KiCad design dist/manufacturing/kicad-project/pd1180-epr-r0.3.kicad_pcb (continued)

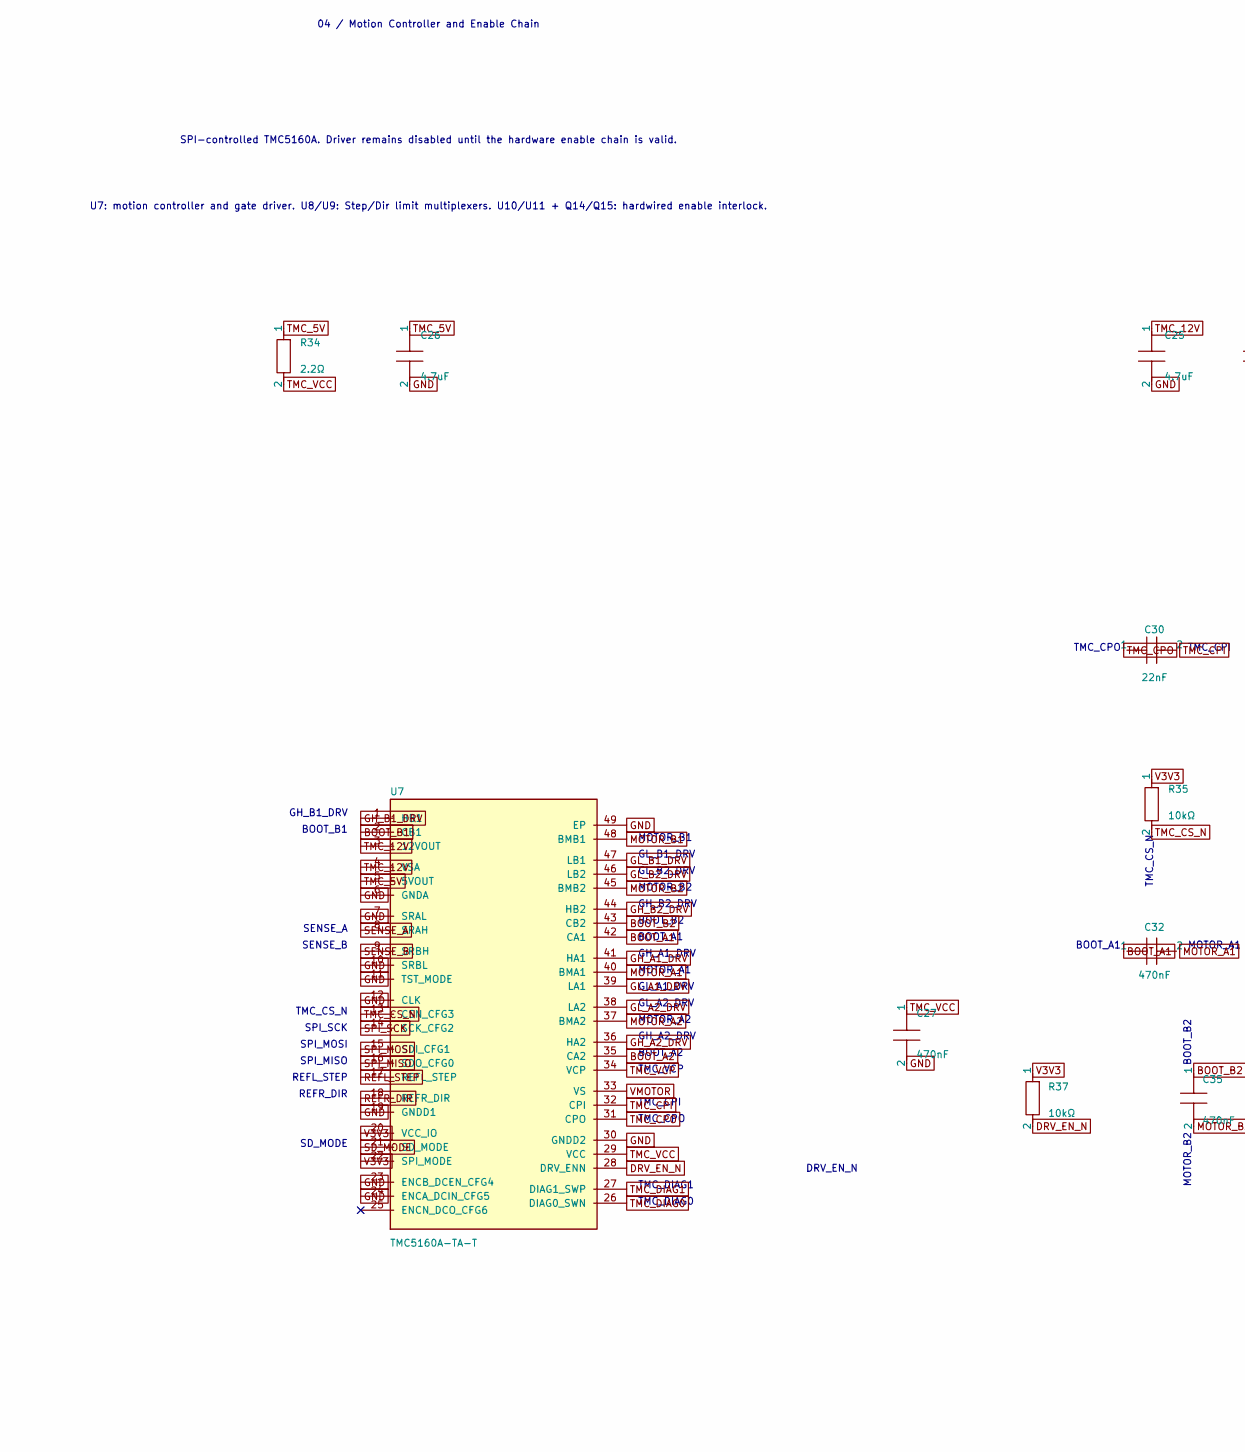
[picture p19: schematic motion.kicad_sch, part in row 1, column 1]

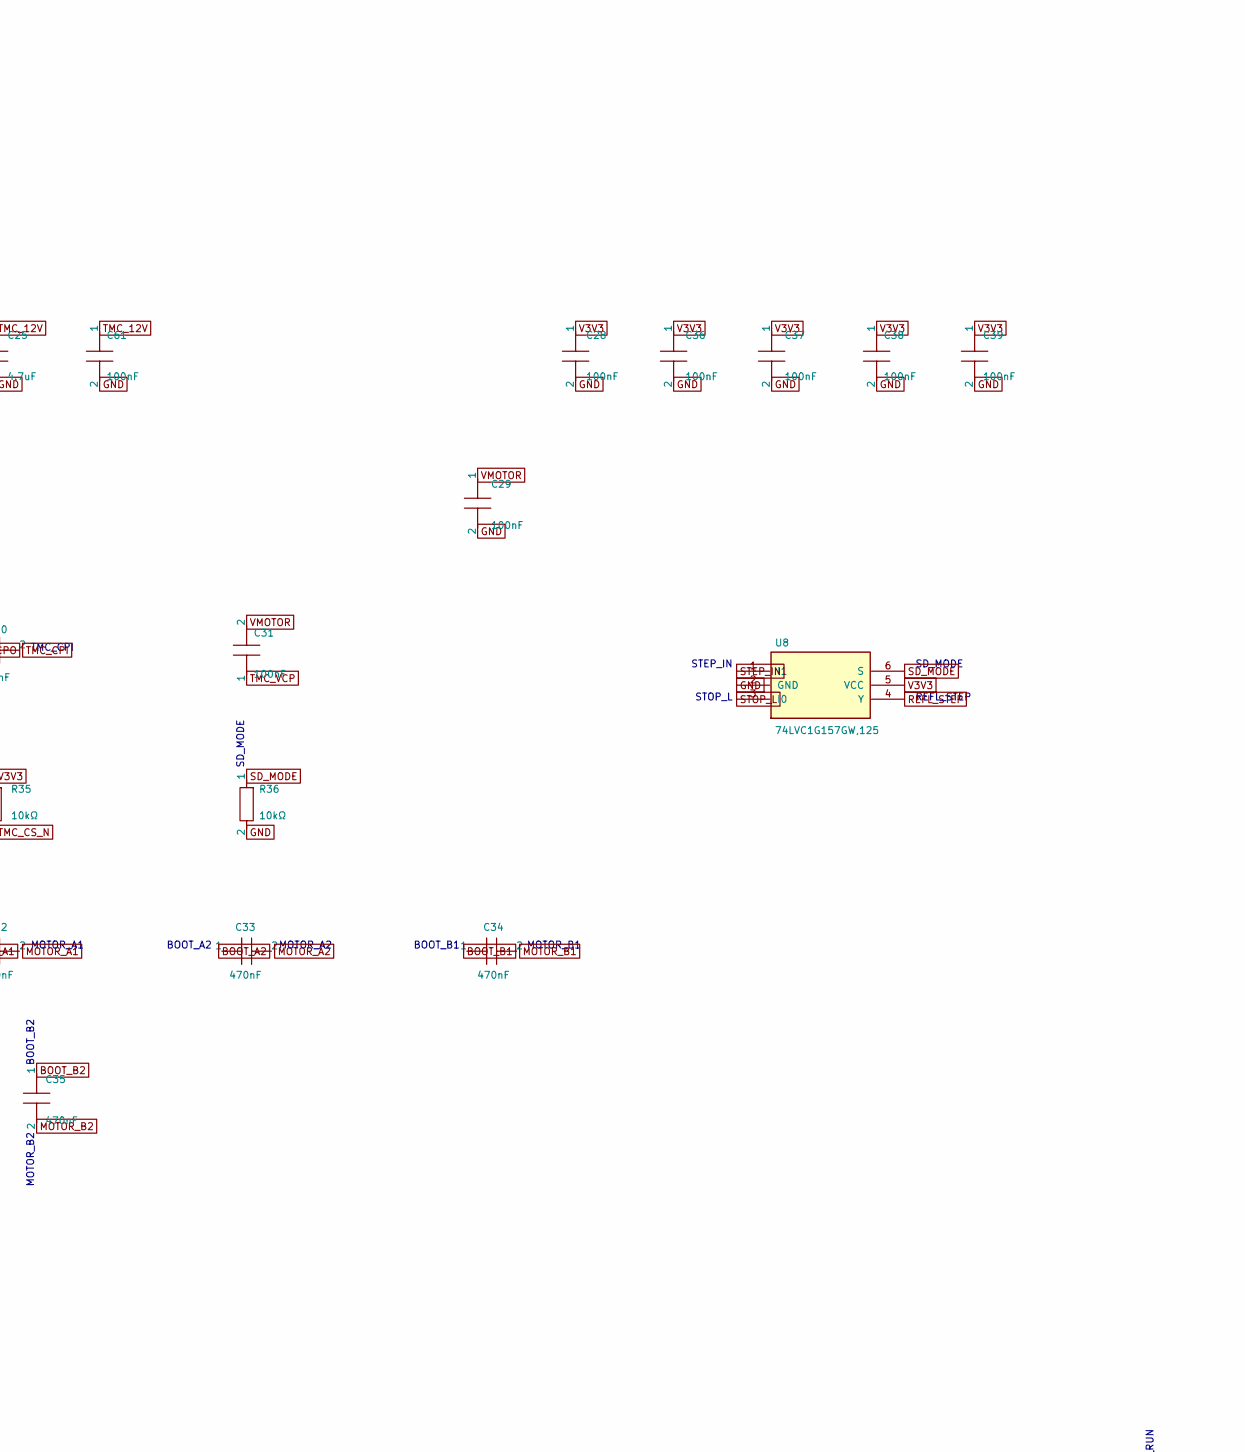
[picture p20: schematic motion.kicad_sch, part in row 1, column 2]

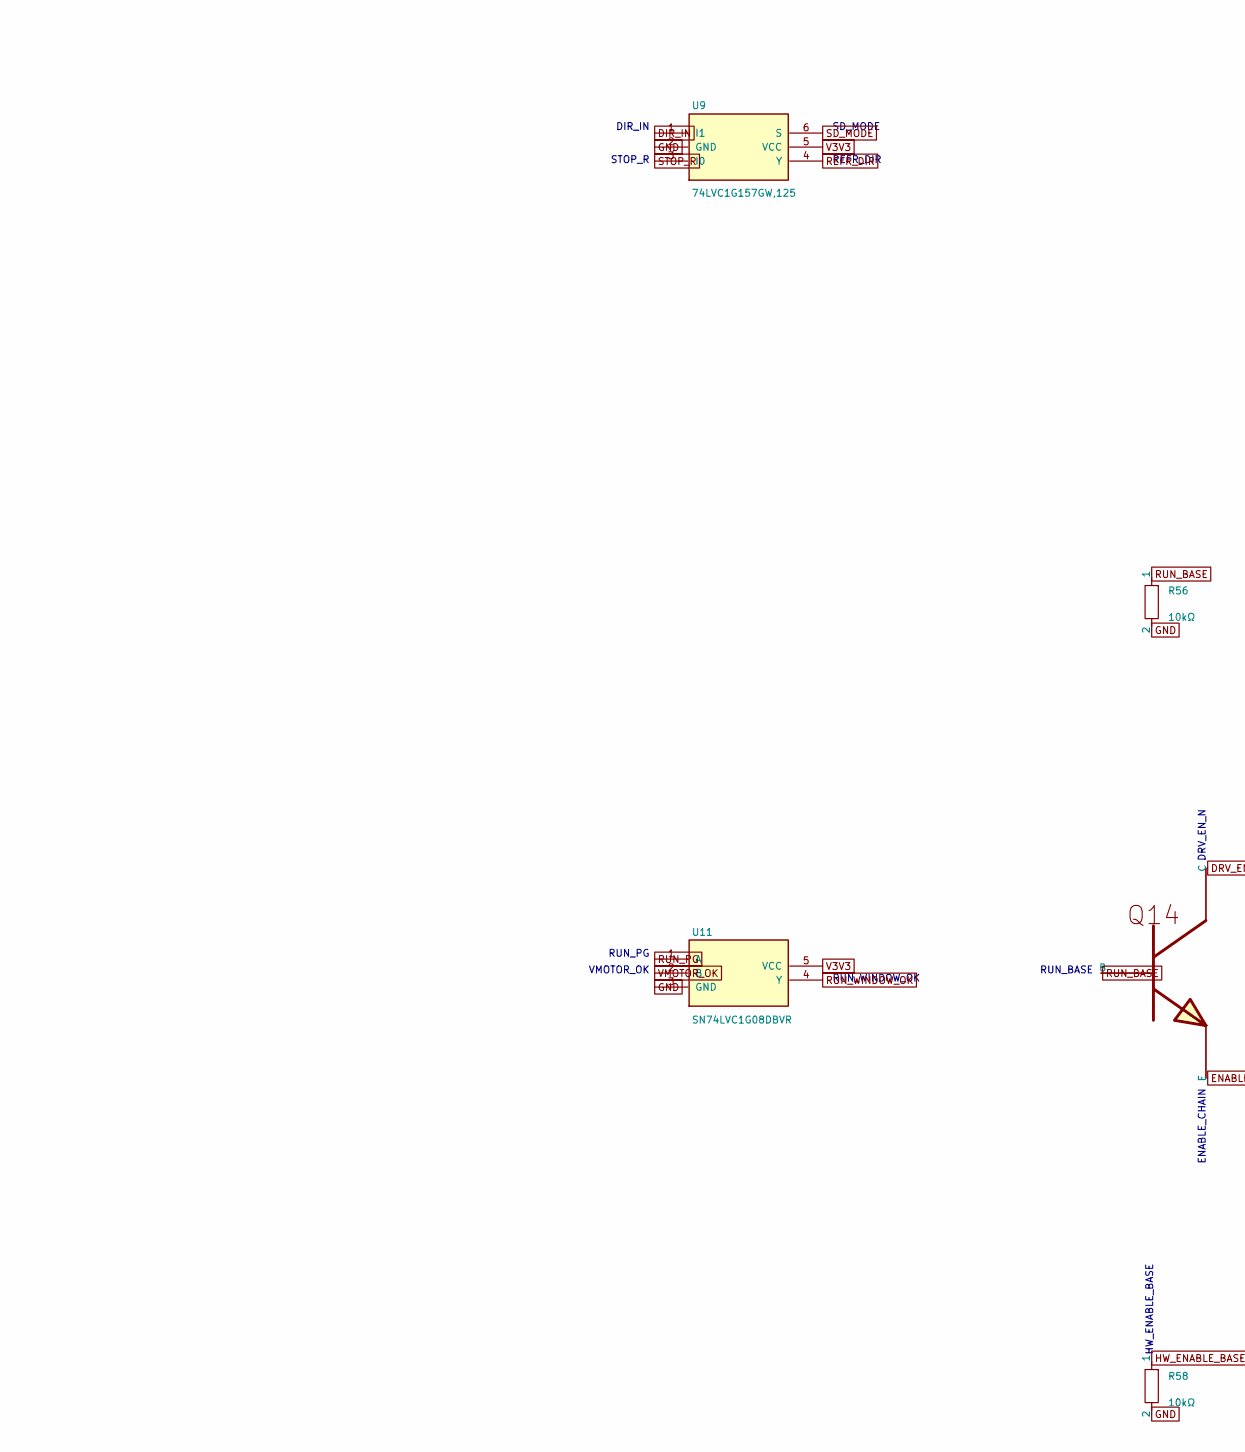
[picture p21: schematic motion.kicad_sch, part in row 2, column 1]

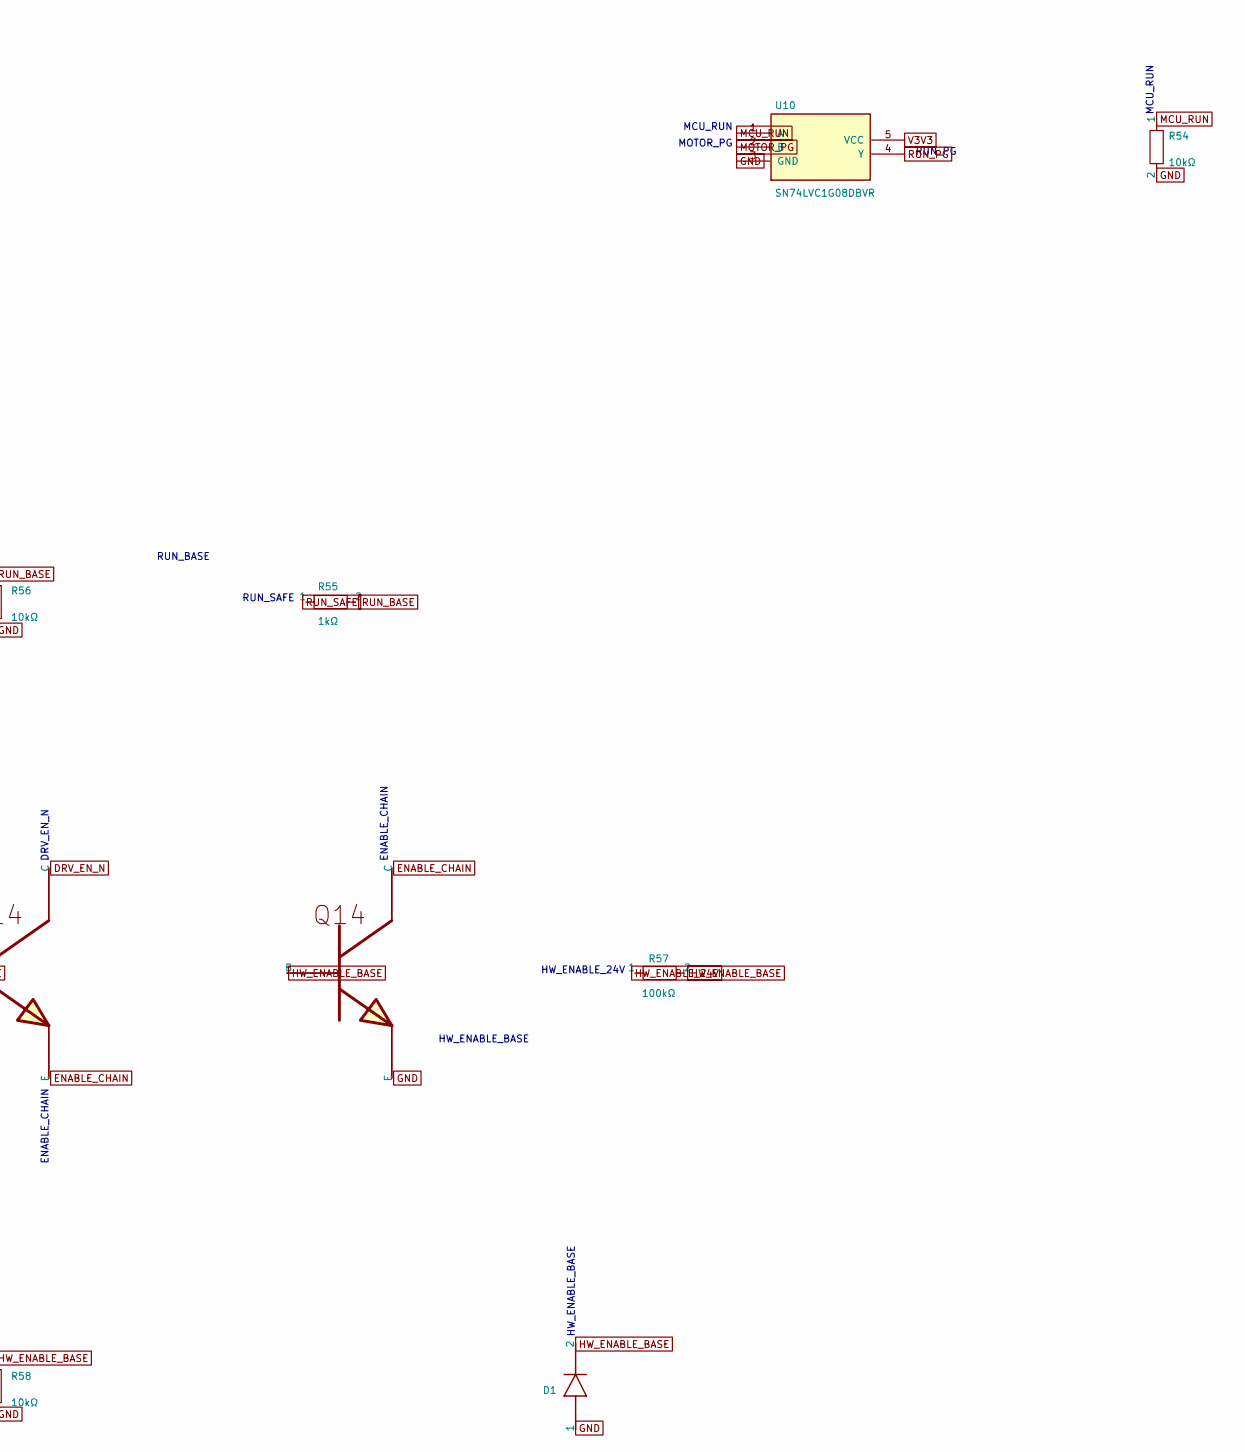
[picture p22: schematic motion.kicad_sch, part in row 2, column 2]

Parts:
C25: 4.7uF; capacitor_cap0805
C26: 4.7uF; capacitor_cap0603
C27, C32, C33, C34, C35: 470nF; capacitor_cap0805
C28, C29, C31, C36, C37, C38, C39, C61: 100nF; capacitor_cap0603
C30: 22nF; capacitor_cap0805
D1: D; BAV21W-7-F
Q14: Q14; MMBT5551LT1G
Q15: Q15; MMBT5551LT1G
R34: 2.2Ω; resistor_res0603
R35, R36, R37, R54, R56, R58: 10kΩ; resistor_res0603
R55: 1kΩ; resistor_res0603
R57: 100kΩ; resistor_res0603
U7: TMC5160A-TA-T
U8, U9: 74LVC1G157GW,125; 74LVC1G157GW_125
U10, U11: SN74LVC1G08DBVR

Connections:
BOOT_A1: C32.1, U7.42 (CA1)
BOOT_A2: C33.1, U7.35 (CA2)
BOOT_B1: C34.1, U7.2 (CB1)
BOOT_B2: C35.1, U7.43 (CB2)
DIR_IN: U9.1 (I1); also elsewhere on the board
DRV_EN_N: Q14.3 (C), R37.2, U7.28 (DRV_ENN)
ENABLE_CHAIN: Q14.2 (E), Q15.3 (C)
GH_A1_DRV: U7.41 (HA1); also elsewhere on the board
GH_A2_DRV: U7.36 (HA2); also elsewhere on the board
GH_B1_DRV: U7.1 (HB1); also elsewhere on the board
GH_B2_DRV: U7.44 (HB2); also elsewhere on the board
GL_A1_DRV: U7.39 (LA1); also elsewhere on the board
GL_A2_DRV: U7.38 (LA2); also elsewhere on the board
GL_B1_DRV: U7.47 (LB1); also elsewhere on the board
GL_B2_DRV: U7.46 (LB2); also elsewhere on the board
GND: C25.2, C26.2, C27.2, C28.2, C29.2, C36.2, C37.2, C38.2, C39.2, C61.2, D1.2 (1), Q15.2 (E), R36.2, R54.2, R56.2, R58.2, U7.6 (GNDA), U7.7 (SRAL), U7.10 (SRBL), U7.11 (TST_MODE), U7.12 (CLK), U7.19 (GNDD1), U7.23 (ENCB_DCEN_CFG4), U7.24 (ENCA_DCIN_CFG5), U7.30 (GNDD2), U7.49 (EP), U8.2 (GND), U9.2 (GND), U10.3 (GND), U11.3 (GND); also elsewhere on the board
HW_ENABLE_24V: R57.1; also elsewhere on the board
HW_ENABLE_BASE: D1.1 (2), Q15.1 (B), R57.2, R58.1
MCU_RUN: R54.1, U10.1 (A); also elsewhere on the board
MOTOR_A1: C32.2, U7.40 (BMA1); also elsewhere on the board
MOTOR_A2: C33.2, U7.37 (BMA2); also elsewhere on the board
MOTOR_B1: C34.2, U7.48 (BMB1); also elsewhere on the board
MOTOR_B2: C35.2, U7.45 (BMB2); also elsewhere on the board
MOTOR_PG: U10.2 (B); also elsewhere on the board
REFL_STEP: U7.17 (REFL_STEP), U8.4 (Y)
REFR_DIR: U7.18 (REFR_DIR), U9.4 (Y)
RUN_BASE: Q14.1 (B), R55.2, R56.1
RUN_PG: U10.4 (Y), U11.1 (A)
RUN_SAFE: R55.1; also elsewhere on the board
RUN_WINDOW_OK: U11.4 (Y); also elsewhere on the board
SD_MODE: R36.1, U7.21 (SD_MODE), U8.6 (S), U9.6 (S); also elsewhere on the board
SENSE_A: U7.8 (SRAH); also elsewhere on the board
SENSE_B: U7.9 (SRBH); also elsewhere on the board
SPI_MISO: U7.16 (SDO_CFG0); also elsewhere on the board
SPI_MOSI: U7.15 (SDI_CFG1); also elsewhere on the board
SPI_SCK: U7.14 (SCK_CFG2); also elsewhere on the board
STEP_IN: U8.1 (I1); also elsewhere on the board
STOP_L: U8.3 (I0); also elsewhere on the board
STOP_R: U9.3 (I0); also elsewhere on the board
TMC_5V: C26.1, R34.1, U7.5 (5VOUT)
TMC_12V: C25.1, C61.1, U7.3 (12VOUT), U7.4 (VSA); also elsewhere on the board
TMC_CPI: C30.2, U7.32 (CPI)
TMC_CPO: C30.1, U7.31 (CPO)
TMC_CS_N: R35.2, U7.13 (CSN_CFG3); also elsewhere on the board
TMC_DIAG0: U7.26 (DIAG0_SWN); also elsewhere on the board
TMC_DIAG1: U7.27 (DIAG1_SWP); also elsewhere on the board
TMC_VCC: C27.1, R34.2, U7.29 (VCC)
TMC_VCP: C31.1, U7.34 (VCP)
V3V3: C28.1, C36.1, C37.1, C38.1, C39.1, R35.1, R37.1, U7.20 (VCC_IO), U7.22 (SPI_MODE), U8.5 (VCC), U9.5 (VCC), U10.5 (VCC), U11.5 (VCC); also elsewhere on the board
VMOTOR: C29.1, C31.2, U7.33 (VS); also elsewhere on the board
VMOTOR_OK: U11.2 (B); also elsewhere on the board

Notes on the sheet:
04 / Motion Controller and Enable Chain
SPI-controlled TMC5160A. Driver remains disabled until the hardware enable chain is valid.
U7: motion controller and gate driver. U8/U9: Step/Dir limit multiplexers. U10/U11 + Q14/Q15: hardwired enable interlock.
GH_B1_DRV
BOOT_B1
SENSE_A
SENSE_B
TMC_CS_N
SPI_SCK
SPI_MOSI
SPI_MISO
REFL_STEP
REFR_DIR
SD_MODE
DRV_EN_N
RUN_BASE
HW_ENABLE_BASE
TMC_DIAG0
TMC_DIAG1
TMC_CPO
TMC_CPI
TMC_VCP
BOOT_A2
GH_A2_DRV
MOTOR_A2
GL_A2_DRV
GL_A1_DRV
MOTOR_A1
GH_A1_DRV
BOOT_A1
BOOT_B2
GH_B2_DRV
MOTOR_B2
GL_B2_DRV
GL_B1_DRV
MOTOR_B1
STEP_IN
STOP_L
DIR_IN
STOP_R


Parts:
J2: J2; B4P-VH_LF_SN
Q6, Q7, Q8, Q9: CSD19534Q5A
R38, R39, R42, R43: 10Ω; resistor_res0603
R40, R41, R44, R45: 100kΩ; resistor_res0603
R109: 33mΩ; HoLLR2512-3W-33mR-1

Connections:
GH_A1: Q6.4 (G), R38.2, R40.1
GH_A1_DRV: R38.1; also elsewhere on the board
GH_A2: Q8.4 (G), R42.2, R44.1
GH_A2_DRV: R42.1; also elsewhere on the board
GL_A1: Q7.4 (G), R39.2, R41.1
GL_A1_DRV: R39.1; also elsewhere on the board
GL_A2: Q9.4 (G), R43.2, R45.1
GL_A2_DRV: R43.1; also elsewhere on the board
GND: R109.2; also elsewhere on the board
MOTOR_A1: Q6.1 (S1), Q6.2 (S2), Q6.3 (S3), Q7.5 (D1), Q7.6 (D2), Q7.7 (D3), Q7.8 (D4), Q7.9 (D5), R40.2; also elsewhere on the board
MOTOR_A1_OUT: J2.1; also elsewhere on the board
MOTOR_A2: J2.2, Q8.1 (S1), Q8.2 (S2), Q8.3 (S3), Q9.5 (D1), Q9.6 (D2), Q9.7 (D3), Q9.8 (D4), Q9.9 (D5), R44.2; also elsewhere on the board
MOTOR_B1_OUT: J2.3; also elsewhere on the board
MOTOR_B2: J2.4; also elsewhere on the board
SENSE_A: Q7.1 (S1), Q7.2 (S2), Q7.3 (S3), Q9.1 (S1), Q9.2 (S2), Q9.3 (S3), R41.2, R45.2, R109.1; also elsewhere on the board
VMOTOR: Q6.5 (D1), Q6.6 (D2), Q6.7 (D3), Q6.8 (D4), Q6.9 (D5), Q8.5 (D1), Q8.6 (D2), Q8.7 (D3), Q8.8 (D4), Q8.9 (D5); also elsewhere on the board

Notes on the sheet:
05 / Motor Phase A Power Bridge
Phase A target 5.5 A RMS; Kelvin sense routing and high-current copper require review.
Q6/Q8: high-side MOSFETs. Q7/Q9: low-side MOSFETs. R109: 33 mOhm, 3 W phase-current shunt.
MOTOR_A1
GH_A1
SENSE_A
GL_A1
MOTOR_A2
GH_A2
GL_A2
GH_A1_DRV
GL_A1_DRV
GH_A2_DRV
GL_A2_DRV
MOTOR_A1_OUT
MOTOR_B1_OUT
MOTOR_B2


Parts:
Q10, Q11, Q12, Q13: CSD19534Q5A
R46, R47, R50, R51: 10Ω; resistor_res0603
R48, R49, R52, R53: 100kΩ; resistor_res0603
R110: 33mΩ; HoLLR2512-3W-33mR-1

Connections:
GH_B1: Q10.4 (G), R46.2, R48.1
GH_B1_DRV: R46.1; also elsewhere on the board
GH_B2: Q12.4 (G), R50.2, R52.1
GH_B2_DRV: R50.1; also elsewhere on the board
GL_B1: Q11.4 (G), R47.2, R49.1
GL_B1_DRV: R47.1; also elsewhere on the board
GL_B2: Q13.4 (G), R51.2, R53.1
GL_B2_DRV: R51.1; also elsewhere on the board
GND: R110.2; also elsewhere on the board
MOTOR_B1: Q10.1 (S1), Q10.2 (S2), Q10.3 (S3), Q11.5 (D1), Q11.6 (D2), Q11.7 (D3), Q11.8 (D4), Q11.9 (D5), R48.2; also elsewhere on the board
MOTOR_B2: Q12.1 (S1), Q12.2 (S2), Q12.3 (S3), Q13.5 (D1), Q13.6 (D2), Q13.7 (D3), Q13.8 (D4), Q13.9 (D5), R52.2; also elsewhere on the board
SENSE_B: Q11.1 (S1), Q11.2 (S2), Q11.3 (S3), Q13.1 (S1), Q13.2 (S2), Q13.3 (S3), R49.2, R53.2, R110.1; also elsewhere on the board
VMOTOR: Q10.5 (D1), Q10.6 (D2), Q10.7 (D3), Q10.8 (D4), Q10.9 (D5), Q12.5 (D1), Q12.6 (D2), Q12.7 (D3), Q12.8 (D4), Q12.9 (D5); also elsewhere on the board

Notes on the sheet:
06 / Motor Phase B Power Bridge
Phase B target 5.5 A RMS; independent 33 milliohm sense resistor.
Q10/Q12: high-side MOSFETs. Q11/Q13: low-side MOSFETs. R110: 33 mOhm, 3 W phase-current shunt.
MOTOR_B1
GH_B1
SENSE_B
GL_B1
MOTOR_B2
GH_B2
GL_B2
GH_B1_DRV
GL_B1_DRV
GH_B2_DRV
GL_B2_DRV

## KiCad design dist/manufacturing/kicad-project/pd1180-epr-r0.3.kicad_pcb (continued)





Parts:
C40, C41, C43, C94: 100nF; capacitor_cap0603
C42, C93: 1uF; capacitor_cap0603
J3: J3; B2P-VH_LF_SN
Q16: CSD19534Q5A
R60: 180kΩ; resistor_res0603
R61: 16kΩ; resistor_res0603
R62: 10kΩ; resistor_res0603
R63: 1MΩ; resistor_res0603
R64: 430kΩ; resistor_res0603
R65: 20kΩ; resistor_res0603
R66: 1kΩ; resistor_res0603
R67, R69: 100kΩ; resistor_res0603
R68: 10Ω; resistor_res0603
U12: REF3425IDBVR
U13, U14: TLV3201AIDBVR
U15: UCC27511DBVR

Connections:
BRAKE_DRIVE: R68.1, U15.2 (OUTH), U15.3 (OUTL)
BRAKE_GATE: Q16.4 (G), R68.2, R69.1
BRAKE_MID: R60.2, R61.1
BRAKE_ON: R63.1, U13.1 (OUT), U15.6 (IN_POS)
BRAKE_RETURN: J3.2, Q16.5 (D1), Q16.6 (D2), Q16.7 (D3), Q16.8 (D4), Q16.9 (D5)
BRAKE_SENSE: R61.2, R62.1, R63.2, U13.3 (IN_POS)
GND: C40.2, C41.2, C42.2, C43.2, C93.2, C94.2, Q16.1 (S1), Q16.2 (S2), Q16.3 (S3), R62.2, R66.2, R67.2, R69.2, U12.1 (GND_F), U12.2 (GND_S), U13.2 (GND), U14.2 (GND), U15.4 (GND), U15.5 (IN_NEG); also elsewhere on the board
MOTOR_OVP_LOW: R65.2, R66.1
MOTOR_OVP_SENSE: R64.2, R65.1, U14.4 (IN_NEG)
TMC_12V: C42.1, C43.1, U15.1 (VDD); also elsewhere on the board
V3V3: C40.1, C41.1, C93.1, U12.3 (ENABLE), U12.4 (IN), U13.5 (VCC), U14.5 (VCC); also elsewhere on the board
VMOTOR: J3.1, R60.1, R64.1; also elsewhere on the board
VMOTOR_OK: R67.1, U14.1 (OUT); also elsewhere on the board
VREF_2V5: C94.1, U12.5 (OUT_S), U12.6 (OUT_F), U13.4 (IN_NEG), U14.3 (IN_POS)

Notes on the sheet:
07 / Regeneration Brake and Overvoltage
Nominal brake threshold 52.0 V; motor inhibit 53.7 V; external resistor sizing depends on total stored mechanical energy.
U12: precision threshold reference. U13/U14: overvoltage comparators. U15: MOSFET gate driver. Q16: brake switch.
VREF_2V5
BRAKE_ON
BRAKE_SENSE
MOTOR_OVP_SENSE
BRAKE_DRIVE
BRAKE_GATE
BRAKE_RETURN
BRAKE_MID
VMOTOR_OK
MOTOR_OVP_LOW


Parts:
C44, C45, C46, C48, C51: 100nF; capacitor_cap0603
C47: 4.7uF; capacitor_cap1206
C49, C50: 12pF; capacitor_cap0603
R70, R73: 10kΩ; resistor_res0603
R71, R72: 22Ω; resistor_res0603
SW1: SW1; TS-1088-AR02016
TP_NRST: TP_NRST; test_point
TP_STATUS: TP_STATUS; test_point
TP_SWCLK: TP_SWCLK; test_point
TP_SWDIO: TP_SWDIO; test_point
TP_SWD_3V3: TP_SWD_3V3; test_point
TP_SWD_GND: TP_SWD_GND; test_point
U16: STM32G0B1CBT6
U17: W25Q32JVSSIQ
Y1: Y1; X322516MLB4SI

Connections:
BOARD_POWER_SENSE: U16.20 (PB1); also elsewhere on the board
CAN_RX: U16.38 (PD0); also elsewhere on the board
CAN_TX: U16.39 (PD1); also elsewhere on the board
DIN0: U16.2 (PC14_OSC32_IN); also elsewhere on the board
DIN1: U16.3 (PC15_OSC32_OUT); also elsewhere on the board
DIR_IN: U16.31 (PC7); also elsewhere on the board
EFUSE_FAULT_N: U16.21 (PB2); also elsewhere on the board
ENC_CS_N: U16.23 (PB11); also elsewhere on the board
FLASH_CS_N: R73.2, U16.24 (PB12), U17.1 (N_CS)
GND: C44.2, C45.2, C46.2, C47.2, C48.2, C49.2, C50.2, C51.2, SW1.2, TP_SWD_GND.1, U16.7 (VSS), U17.4 (GND), Y1.2, Y1.4; also elsewhere on the board
HOME_IN: U16.27 (PB15); also elsewhere on the board
MCU_RUN: U16.37 (PA15); also elsewhere on the board
MOTOR_PG: U16.43 (PB4); also elsewhere on the board
NRST: C48.1, R70.2, SW1.1, TP_NRST.1, U16.10 (PF2_NRST)
OSC_IN: C49.1, U16.8 (PF0_OSC_IN), Y1.1
OSC_OUT: C50.1, U16.9 (PF1_OSC_OUT), Y1.3
OUT0_DRIVE: U16.40 (PD2); also elsewhere on the board
OUT1_DRIVE: U16.41 (PD3); also elsewhere on the board
PD_SCL: U16.45 (PB6); also elsewhere on the board
PD_SDA: U16.46 (PB7); also elsewhere on the board
PHASE_A_ADC: U16.11 (PA0); also elsewhere on the board
PHASE_B_ADC: U16.12 (PA1); also elsewhere on the board
POWER_PERMIT: U16.44 (PB5); also elsewhere on the board
RS232_RX: U16.32 (PA10); also elsewhere on the board
RS232_TX: U16.29 (PA9); also elsewhere on the board
RS485_DE: U16.22 (PB10); also elsewhere on the board
RS485_RX: U16.14 (PA3); also elsewhere on the board
RS485_TX: U16.13 (PA2); also elsewhere on the board
SD_MODE: U16.28 (PA8); also elsewhere on the board
SPI_MISO: U16.17 (PA6), U17.2 (DO_IO1); also elsewhere on the board
SPI_MOSI: U16.18 (PA7), U17.5 (DI_IO0); also elsewhere on the board
SPI_SCK: U16.16 (PA5), U17.6 (CLK); also elsewhere on the board
STATUS_GPIO: TP_STATUS.1, U16.1 (PC13)
STEP_IN: U16.30 (PC6); also elsewhere on the board
STOP_L: U16.25 (PB13); also elsewhere on the board
STOP_R: U16.26 (PB14); also elsewhere on the board
SWCLK: TP_SWCLK.1, U16.36 (PA14_BOOT0)
SWDIO: TP_SWDIO.1, U16.35 (PA13)
TMC_CS_N: U16.15 (PA4); also elsewhere on the board
TMC_DIAG0: U16.42 (PB3); also elsewhere on the board
TMC_DIAG1: U16.47 (PB8); also elsewhere on the board
USB_DM: R72.2, U16.33 (PA11_PA9_)
USB_DM_CONN: R72.1; also elsewhere on the board
USB_DP: R71.2, U16.34 (PA12_PA10_)
USB_DP_CONN: R71.1; also elsewhere on the board
USB_VBUS_SENSE: U16.19 (PB0); also elsewhere on the board
V3V3: C51.1, R73.1, U17.3 (WP__IO2), U17.7 (HOLD__or_RESET__IO3), U17.8 (VCC); also elsewhere on the board
V3V3_MCU: C44.1, C45.1, C46.1, C47.1, R70.1, TP_SWD_3V3.1, U16.4 (VBAT), U16.5 (VREF_POS), U16.6 (VDD); also elsewhere on the board
VMOTOR_OK: U16.48 (PB9); also elsewhere on the board

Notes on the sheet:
08 / MCU, Clock, Memory and Debug
3.3 V STM32G0B1; USB diagnostics, SWD, SPI motion control and external STEP/DIR.
U16: system MCU with native USB, FDCAN and ADC monitoring. U17: 32 Mbit external SPI configuration/telemetry flash.
STATUS_GPIO
DIN0
DIN1
OSC_IN
OSC_OUT
NRST
FLASH_CS_N
PHASE_A_ADC
PHASE_B_ADC
RS485_TX
RS485_RX
TMC_CS_N
SPI_SCK
SPI_MISO
SPI_MOSI
USB_VBUS_SENSE
BOARD_POWER_SENSE
EFUSE_FAULT_N
RS485_DE
ENC_CS_N
STOP_L
STOP_R
HOME_IN
SD_MODE
RS232_TX
STEP_IN
DIR_IN
RS232_RX
USB_DM
USB_DP
SWDIO
SWCLK
MCU_RUN
CAN_RX
CAN_TX
OUT0_DRIVE
OUT1_DRIVE

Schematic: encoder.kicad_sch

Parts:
C52: 100nF; capacitor_cap0603
C53: 1uF; capacitor_cap0603
R74: 10kΩ; resistor_res0603
TP_ENC_3V3: TP_ENC_3V3; test_point
TP_ENC_A: TP_ENC_A; test_point
TP_ENC_B: TP_ENC_B; test_point
TP_ENC_GND: TP_ENC_GND; test_point
TP_ENC_I: TP_ENC_I; test_point
U18: AS5047P-ATSM

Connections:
ENC_A: TP_ENC_A.1, U18.7 (A)
ENC_B: TP_ENC_B.1, U18.6 (B)
ENC_CS_N: R74.2, U18.1 (CSn); also elsewhere on the board
ENC_I: TP_ENC_I.1, U18.14 (I)
GND: C52.2, C53.2, TP_ENC_GND.1, U18.5 (Test), U18.13 (GND); also elsewhere on the board
SPI_MISO: U18.3 (MISO); also elsewhere on the board
SPI_MOSI: U18.4 (MOSI); also elsewhere on the board
SPI_SCK: U18.2 (CLK); also elsewhere on the board
V3V3: C52.1, C53.1, R74.1, TP_ENC_3V3.1, U18.11 (VDD), U18.12 (VDD3V3); also elsewhere on the board

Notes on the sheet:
09 / Shaft Encoder and Monitor
AS5047P is centered on the PCB underside; shaft magnet alignment must be verified.
U18: 14-bit magnetic shaft encoder; SPI readout plus ABI incremental outputs and local 3.3 V filtering.
ENC_CS_N
SPI_SCK
SPI_MISO
SPI_MOSI
ENC_B
ENC_A
ENC_I

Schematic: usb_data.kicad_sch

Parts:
C72, C73: 100nF; capacitor_cap0603
D15: USBLC6-4SC6
J10: J10; USB4105-GF-A
R105, R106: 5.1kΩ; resistor_res0603
R107: 1MΩ; resistor_res0603
R108: 47kΩ; resistor_res0603

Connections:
DATA_CC1: D15.4, J10.15 (CC1), R105.1
DATA_CC2: D15.6, J10.9 (CC2), R106.1
GND: C72.2, C73.2, D15.2, J10.1 (EH1), J10.2 (GND1), J10.3 (GND1), J10.4 (GND1), J10.5 (GND1), J10.6 (GND1), J10.19 (GND1), J10.20 (GND1), R105.2, R106.2, R108.2; also elsewhere on the board
USB_DATA_VBUS: C73.1, D15.5, J10.7 (VBUS), J10.8 (VBUS), J10.17 (VBUS), J10.18 (VBUS), R107.1; also elsewhere on the board
USB_DM_CONN: D15.3, J10.12 (DM), J10.14 (DM); also elsewhere on the board
USB_DP_CONN: D15.1, J10.11 (DP), J10.13 (DP); also elsewhere on the board
USB_VBUS_SENSE: C72.1, R107.2, R108.1; also elsewhere on the board

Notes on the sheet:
10 / USB DATA and Attach Sense
J10: USB 2.0 DATA plus independent logic power. Separate CC pulldowns; no PD negotiation on this port.
D15: D+/D-/CC ESD. R107/R108/C72: DATA VBUS attach sense. USB DATA cannot feed VMOTOR.
USB_VBUS_SENSE
DATA_CC2
DATA_CC1
USB_DM_CONN
USB_DP_CONN

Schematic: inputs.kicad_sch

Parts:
D4, D5, D6, D7, D8, D9, D10: D; BAV21W-7-F
J7: B20B-PHDSS(LF)(SN); B20B-PHDSS_LF_SN
Q17: Q17; MMBT5551LT1G
Q18: Q18; MMBT5551LT1G
Q19: Q19; MMBT5551LT1G
Q20: Q20; MMBT5551LT1G
Q21: Q21; MMBT5551LT1G
Q22: Q22; MMBT5551LT1G
Q23: Q23; MMBT5551LT1G
R77, R80, R83, R86, R89, R92, R95: 47kΩ; resistor_res0603
R78, R81, R84, R87, R90, R93, R96: 10kΩ; resistor_res0603
R79, R82, R85, R88, R91, R94, R97: 4.7kΩ; resistor_res0603

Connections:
CAN_H: J7.12; also elsewhere on the board
CAN_L: J7.13; also elsewhere on the board
DIN0: Q17.3 (C), R79.2; also elsewhere on the board
DIN0_24V: J7.4, R77.1
DIN0_BASE: D4.1 (2), Q17.1 (B), R77.2, R78.1
DIN1: Q18.3 (C), R82.2; also elsewhere on the board
DIN1_24V: J7.5, R80.1
DIN1_BASE: D5.1 (2), Q18.1 (B), R80.2, R81.1
DIR_24V: J7.7, R95.1
DIR_IN: Q23.3 (C), R97.2; also elsewhere on the board
DIR_IN_BASE: D10.1 (2), Q23.1 (B), R95.2, R96.1
GND: D4.2 (1), D5.2 (1), D6.2 (1), D7.2 (1), D8.2 (1), D9.2 (1), D10.2 (1), J7.8, J7.11, J7.14, Q17.2 (E), Q18.2 (E), Q19.2 (E), Q20.2 (E), Q21.2 (E), Q22.2 (E), Q23.2 (E), R78.2, R81.2, R84.2, R87.2, R90.2, R93.2, R96.2; also elsewhere on the board
HOME_24V: J7.1, R89.1
HOME_IN: Q21.3 (C), R91.2; also elsewhere on the board
HOME_IN_BASE: D8.1 (2), Q21.1 (B), R89.2, R90.1
HW_ENABLE_24V: J7.18; also elsewhere on the board
OUT0: J7.19; also elsewhere on the board
OUT1: J7.20; also elsewhere on the board
RS232_RX_CONN: J7.10; also elsewhere on the board
RS232_TX_CONN: J7.9; also elsewhere on the board
RS485_A: J7.15; also elsewhere on the board
RS485_B: J7.16; also elsewhere on the board
STEP_24V: J7.6, R92.1
STEP_IN: Q22.3 (C), R94.2; also elsewhere on the board
STEP_IN_BASE: D9.1 (2), Q22.1 (B), R92.2, R93.1
STOPL_24V: J7.2, R83.1
STOPR_24V: J7.3, R86.1
STOP_L: Q19.3 (C), R85.2; also elsewhere on the board
STOP_L_BASE: D6.1 (2), Q19.1 (B), R83.2, R84.1
STOP_R: Q20.3 (C), R88.2; also elsewhere on the board
STOP_R_BASE: D7.1 (2), Q20.1 (B), R86.2, R87.1
V3V3: R79.1, R82.1, R85.1, R88.1, R91.1, R94.1, R97.1; also elsewhere on the board
VMOTOR: J7.17; also elsewhere on the board

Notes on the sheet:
11 / 24 V Inputs and Step/Direction
Non-isolated 24 V inputs. J7: keyed 20-pin harness combines all control I/O and industrial buses; pinout is in hardware-contract.json.
Q17-Q23: HOME, limits, DIN0/1 and Step/Direction conditioners. Q14: hardware enable on the motion sheet.
HOME_24V
STOPL_24V
STOPR_24V
DIN0_24V
DIN1_24V
STEP_24V
DIR_24V
RS232_TX_CONN
RS232_RX_CONN
CAN_H
CAN_L
RS485_A
RS485_B
HW_ENABLE_24V
OUT0
OUT1
STOP_L
STOP_L_BASE
STOP_R_BASE
HOME_IN_BASE
STEP_IN_BASE
DIR_IN_BASE
DIN0_BASE
DIN1_BASE
STOP_R
HOME_IN
STEP_IN
DIR_IN
DIN0
DIN1

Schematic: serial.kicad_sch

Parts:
C54, C55, C56, C57, C58, C59, C60: 100nF; capacitor_cap0603
D2: SM24CANB-02HTG
D3: PSM712-LF-T7
R75, R76: 10kΩ; resistor_res0603
U19: TCAN332DR
U20: MAX3485EESA+T; MAX3485EESA_T
U21: MAX3232ESE+T; MAX3232ESE_T

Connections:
CAN_H: D2.1, U19.7 (CANH); also elsewhere on the board
CAN_L: D2.2, U19.6 (CANL); also elsewhere on the board
CAN_RX: U19.4 (RXD); also elsewhere on the board
CAN_TX: R75.2, U19.1 (TXD); also elsewhere on the board
GND: C54.2, C55.2, C58.2, C59.2, C60.2, D2.3, D3.3 (K), R76.2, U19.2 (GND), U20.5 (GND), U21.8 (R2IN), U21.10 (T2IN), U21.15 (GND); also elsewhere on the board
RS232_C1N: C56.2, U21.3 (C1_NEG)
RS232_C1P: C56.1, U21.1 (C1_POS)
RS232_C2N: C57.2, U21.5 (C2_NEG)
RS232_C2P: C57.1, U21.4 (C2_POS)
RS232_RX: U21.12 (R1OUT); also elsewhere on the board
RS232_RX_CONN: U21.13 (R1IN); also elsewhere on the board
RS232_TX: U21.11 (T1IN); also elsewhere on the board
RS232_TX_CONN: U21.14 (T1OUT); also elsewhere on the board
RS232_VN: C59.1, U21.6 (V_NEG)
RS232_VP: C58.1, U21.2 (V_POS)
RS485_A: D3.1 (A11), U20.6 (A); also elsewhere on the board
RS485_B: D3.2 (A12), U20.7 (B); also elsewhere on the board
RS485_DE: R76.1, U20.2 (N_RE), U20.3 (DE); also elsewhere on the board
RS485_RX: U20.1 (RO); also elsewhere on the board
RS485_TX: U20.4 (DI); also elsewhere on the board
V3V3: C54.1, C55.1, C60.1, R75.1, U19.3 (VCC), U20.8 (VCC), U21.16 (VCC); also elsewhere on the board

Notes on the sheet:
12 / CAN, RS485 and RS232
External CAN/RS485 termination; J7 carries RS232, CAN and RS485.
U19: 3.3 V CAN transceiver; D2: CAN TVS. U20: RS485 transceiver; D3: RS485 TVS. U21: RS232 transceiver.
CAN_TX
CAN_RX
CAN_L
CAN_H
RS485_RX
RS485_DE
RS485_TX
RS485_A
RS485_B
RS232_C1P
RS232_VP
RS232_C1N
RS232_C2P
RS232_C2N
RS232_VN
RS232_TX
RS232_RX
RS232_RX_CONN
RS232_TX_CONN

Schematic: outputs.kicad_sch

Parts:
D11, D12: D; SS110
Q24: Q24; MMBT5551LT1G
Q25: Q25; MMBT5551LT1G
R98, R100: 1kΩ; resistor_res0603
R99, R101: 10kΩ; resistor_res0603

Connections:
GND: Q24.2 (E), Q25.2 (E), R99.2, R101.2; also elsewhere on the board
OUT0: D11.2 (1), Q24.3 (C); also elsewhere on the board
OUT0_BASE: Q24.1 (B), R98.2, R99.1
OUT0_DRIVE: R98.1; also elsewhere on the board
OUT1: D12.2 (1), Q25.3 (C); also elsewhere on the board
OUT1_BASE: Q25.1 (B), R100.2, R101.1
OUT1_DRIVE: R100.1; also elsewhere on the board
VMOTOR: D11.1 (2), D12.1 (2); also elsewhere on the board

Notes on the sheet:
13 / Hardware Enable and Outputs
J7: motor rail, 24 V hardware enable, OUT0 and OUT1. External loads need rating review.
Q24/Q25: open-collector 24 V output drivers; base pulldowns keep outputs off during reset.
OUT0
OUT0_BASE
OUT1_BASE
OUT0_DRIVE
OUT1
OUT1_DRIVE

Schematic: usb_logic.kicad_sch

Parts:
C74, C77, C78: 100nF; capacitor_cap0603
C75: 1uF; capacitor_cap0603
C76: 10uF; capacitor_cap0603
R112, R119, R120: 10kΩ; resistor_res0603
R113: 100kΩ; resistor_res0603
U25: TLV75533PDBVR
U26, U27: LM66100DCKR
U28: TPS2553DBVR

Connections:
BOARD_POWER_SENSE: R119.2, R120.1; also elsewhere on the board
GND: C74.2, C75.2, C76.2, C77.2, C78.2, R113.2, R120.2, U25.2 (GND), U26.2 (GND), U27.2 (GND), U27.5 (ST), U28.2 (GND); also elsewhere on the board
USB_DATA_VBUS: C74.1, U28.1 (IN), U28.3 (EN); also elsewhere on the board
USB_ILIM: R113.1, U28.5 (ILIM)
USB_LOGIC_5V: C75.1, U25.1 (IN), U25.3 (EN), U28.6 (OUT)
USB_OR_SELECT: R112.2, U26.5 (ST), U27.3 (N_CE)
V3V3: C77.1, R112.1, R119.1, U26.1 (VIN); also elsewhere on the board
V3V3_MCU: U26.6 (VOUT), U27.6 (VOUT); also elsewhere on the board
V3V3_USB: C76.1, C78.1, U25.5 (OUT), U26.3 (N_CE), U27.1 (VIN)

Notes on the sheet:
14 / USB Logic Power
U28: DATA current limiter. U25: 3.3 V LDO. DATA powers MCU only; peripherals require board power.
U26/U27: reverse-blocked V3V3_MCU. R119/R120 sense board power on PB1; PD status is polled.
BOARD_POWER_SENSE
USB_ILIM
USB_OR_SELECT

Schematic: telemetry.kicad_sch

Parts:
C79, C80, C81, C82, C85: 100nF; capacitor_cap0603
C83, C84: 10nF; capacitor_cap0603
R114: 10kΩ; resistor_res0603
R115, R116: 5mΩ; FRM121WFR005TM
R117, R118: 1kΩ; resistor_res0603
U29: TMP102AIDRLR
U30: ADS1115IDGSR
U31, U32: INA240A1DR
U33: SN74LVC1G08DBVR

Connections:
GND: C79.2, C80.2, C81.2, C82.2, C83.2, C84.2, C85.2, U29.2 (GND), U29.4 (ADD0), U30.3 (GND), U30.6 (AIN2), U30.7 (AIN3), U31.2 (GND), U31.3 (REF2), U32.2 (GND), U32.3 (REF2), U33.3 (GND); also elsewhere on the board
IIN_MON: U30.5 (AIN1); also elsewhere on the board
MOTOR_A1: R115.1, U31.8 (IN_POS); also elsewhere on the board
MOTOR_A1_OUT: R115.2, U31.1 (IN_NEG); also elsewhere on the board
MOTOR_B1: R116.1, U32.8 (IN_POS); also elsewhere on the board
MOTOR_B1_OUT: R116.2, U32.1 (IN_NEG); also elsewhere on the board
PD_SCL: U29.1 (SCL), U30.10 (SCL); also elsewhere on the board
PD_SDA: U29.6 (SDA), U30.9 (SDA); also elsewhere on the board
PHASE_A_ADC: C83.1, R117.2; also elsewhere on the board
PHASE_A_RAW: R117.1, U31.5 (OUT)
PHASE_B_ADC: C84.1, R118.2; also elsewhere on the board
PHASE_B_RAW: R118.1, U32.5 (OUT)
RUN_SAFE: U33.4 (Y); also elsewhere on the board
RUN_WINDOW_OK: U33.1 (A); also elsewhere on the board
TEMP_OK: R114.2, U29.3 (ALERT), U33.2 (B)
V3V3: C79.1, C80.1, C81.1, C82.1, C85.1, R114.1, U29.5 (V_POS), U30.1 (ADDR), U30.8 (VDD), U31.6 (VS), U31.7 (REF1), U32.6 (VS), U32.7 (REF1), U33.5 (VCC); also elsewhere on the board
VMON_ADC: U30.4 (AIN0); also elsewhere on the board

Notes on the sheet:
15 / Temperature and Current Diagnostics
U29: power-stage temperature, address 0x48. U33: temperature hardware inhibit. U30: bus-monitor ADC, address 0x49.
U31/U32: bidirectional winding telemetry, 20 V/V across 5 mOhm = 100 mV/A, centered at 1.65 V. Not a short-circuit trip.
PD_SCL
TEMP_OK
PD_SDA
RUN_WINDOW_OK
RUN_SAFE
VMON_ADC
IIN_MON
MOTOR_A1_OUT
PHASE_A_RAW
MOTOR_A1
PHASE_A_ADC
MOTOR_B1_OUT
PHASE_B_RAW
MOTOR_B1
PHASE_B_ADC

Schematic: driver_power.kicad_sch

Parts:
C86: 2.2uF; capacitor_cap1206
C87: 220nF; capacitor_cap0805
C88: 1uF; capacitor_cap0603
C89: 100nF; capacitor_cap0603
C90, C91, C92: 22uF; capacitor_cap0805
L3: 47µH; SRP7050TA-470M
R121: 100kΩ; resistor_res0603
R122: 9.09kΩ; resistor_res0603
U34: LMR36510ADDAR

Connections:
DRIVER_BUCK_BOOT: C89.1, U34.7 (BOOT)
DRIVER_BUCK_FB: R121.2, R122.1, U34.5 (FB)
DRIVER_BUCK_SW: C89.2, L3.1, U34.8 (SW)
DRIVER_BUCK_VCC: C88.1, U34.6 (VCC)
GND: C86.2, C87.2, C88.2, C90.2, C91.2, C92.2, R122.2, U34.1 (PGND), U34.9 (PAD); also elsewhere on the board
TMC_12V: C90.1, C91.1, C92.1, L3.2, R121.1; also elsewhere on the board
VMOTOR: C86.1, C87.1, U34.2 (VIN), U34.3 (EN); also elsewhere on the board

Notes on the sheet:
16 / Regulated Driver Supply
U34: 65 V buck, nominal 12.0 V. Supplies U7 VSA + 12VOUT and U15; derived from protected VMOTOR.
TMC5160A external-regulator connection: 10-13 V operating range. Gate-supply ripple and startup need bench validation.
DRIVER_BUCK_FB
DRIVER_BUCK_SW
DRIVER_BUCK_BOOT


Board: 4 copper layers, 85.9 x 85.9 mm, 305 parts (0 on the bottom side), 199 nets.

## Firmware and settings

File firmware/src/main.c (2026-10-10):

#include "board_pins.h"
#include "control.h"
#include "tmc5160_config.h"

#include <stdio.h>

int main(void) {
  pd1180_control_t control;
  pd1180_control_reset(&control);
  const pd1180_inputs_t inputs = {
    .pd_app_mode = true,
    .epr_contract = true,
    .contract_mv = 48000,
    .contract_ma = 5000,
    .motor_power_good = true,
    .vmotor_in_range = true,
    .watchdog_healthy = true,
    .configuration_verified = true, .sample_fresh = true, .driver_ready = true, .motion_wiring_verified = true,
    .temperature_valid = true, .temperature_deci_c = 250,
  };
  if (!pd1180_control_arm(&control, &inputs)) return 1;
  for (unsigned elapsed = 0; elapsed < 350; elapsed += 10) pd1180_control_tick(&control, &inputs, 10);
  printf("permit=%u run=%u tmc_registers=%zu mcu_run_pin=P%c%u\n",
    control.power_permit, control.mcu_run, pd1180_tmc5160_boot_config_count,
    PD1180_PIN_MCU_RUN.port, PD1180_PIN_MCU_RUN.bit);
  return control.motor_commands_enabled ? 0 : 1;
}

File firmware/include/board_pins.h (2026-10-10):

#pragma once

#include <stdint.h>

typedef struct { char port; uint8_t bit; uint8_t package_pin; } board_pin_t;

#define BOARD_PIN(PORT, BIT, PACKAGE_PIN) ((board_pin_t){ (PORT), (BIT), (PACKAGE_PIN) })

#define PD1180_PIN_STATUS_GPIO       BOARD_PIN('C', 13, 1)
#define PD1180_PIN_DIN0              BOARD_PIN('C', 14, 2)
#define PD1180_PIN_DIN1              BOARD_PIN('C', 15, 3)
#define PD1180_PIN_OSC_IN            BOARD_PIN('F', 0, 8)
#define PD1180_PIN_OSC_OUT           BOARD_PIN('F', 1, 9)
#define PD1180_PIN_NRST              BOARD_PIN('F', 2, 10)
#define PD1180_PIN_PHASE_A_ADC       BOARD_PIN('A', 0, 11)
#define PD1180_PIN_PHASE_B_ADC       BOARD_PIN('A', 1, 12)
#define PD1180_PIN_RS485_TX          BOARD_PIN('A', 2, 13)
#define PD1180_PIN_RS485_RX          BOARD_PIN('A', 3, 14)
#define PD1180_PIN_TMC_CS_N          BOARD_PIN('A', 4, 15)
#define PD1180_PIN_SPI_SCK           BOARD_PIN('A', 5, 16)
#define PD1180_PIN_SPI_MISO          BOARD_PIN('A', 6, 17)
#define PD1180_PIN_SPI_MOSI          BOARD_PIN('A', 7, 18)
#define PD1180_PIN_USB_VBUS_SENSE    BOARD_PIN('B', 0, 19)
#define PD1180_PIN_BOARD_POWER_SENSE BOARD_PIN('B', 1, 20)
#define PD1180_PIN_EFUSE_FAULT_N     BOARD_PIN('B', 2, 21)
#define PD1180_PIN_RS485_DE          BOARD_PIN('B', 10, 22)
#define PD1180_PIN_ENC_CS_N          BOARD_PIN('B', 11, 23)
#define PD1180_PIN_FLASH_CS_N        BOARD_PIN('B', 12, 24)
#define PD1180_PIN_STOP_L            BOARD_PIN('B', 13, 25)
#define PD1180_PIN_STOP_R            BOARD_PIN('B', 14, 26)
#define PD1180_PIN_HOME_IN           BOARD_PIN('B', 15, 27)
#define PD1180_PIN_SD_MODE           BOARD_PIN('A', 8, 28)
#define PD1180_PIN_RS232_TX          BOARD_PIN('A', 9, 29)
#define PD1180_PIN_STEP_IN           BOARD_PIN('C', 6, 30)
#define PD1180_PIN_DIR_IN            BOARD_PIN('C', 7, 31)
#define PD1180_PIN_RS232_RX          BOARD_PIN('A', 10, 32)
#define PD1180_PIN_USB_DM            BOARD_PIN('A', 11, 33)
#define PD1180_PIN_USB_DP            BOARD_PIN('A', 12, 34)
#define PD1180_PIN_SWDIO             BOARD_PIN('A', 13, 35)
#define PD1180_PIN_SWCLK             BOARD_PIN('A', 14, 36)
#define PD1180_PIN_MCU_RUN           BOARD_PIN('A', 15, 37)
#define PD1180_PIN_CAN_RX            BOARD_PIN('D', 0, 38)
#define PD1180_PIN_CAN_TX            BOARD_PIN('D', 1, 39)
#define PD1180_PIN_OUT0_DRIVE        BOARD_PIN('D', 2, 40)
#define PD1180_PIN_OUT1_DRIVE        BOARD_PIN('D', 3, 41)
#define PD1180_PIN_TMC_DIAG0         BOARD_PIN('B', 3, 42)
#define PD1180_PIN_MOTOR_PG          BOARD_PIN('B', 4, 43)
#define PD1180_PIN_POWER_PERMIT      BOARD_PIN('B', 5, 44)
#define PD1180_PIN_PD_SCL            BOARD_PIN('B', 6, 45)
#define PD1180_PIN_PD_SDA            BOARD_PIN('B', 7, 46)
#define PD1180_PIN_TMC_DIAG1         BOARD_PIN('B', 8, 47)
#define PD1180_PIN_VMOTOR_OK         BOARD_PIN('B', 9, 48)

#define BOARD_HSE_HZ 16000000u
#define BOARD_USB_CLOCK_HZ 48000000u

/* Generated from docs/firmware-pinmap.json; do not edit by hand. */

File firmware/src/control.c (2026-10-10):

#include "control.h"
#include "telemetry.h"

#define CONTRACT_STABLE_REQUIRED_MS 100u
#define MOTOR_STABLE_REQUIRED_MS 200u
#define REQUIRED_CONTRACT_MV 48000u
#define REQUIRED_CONTRACT_MA 5000u

static uint32_t saturating_add(uint32_t value, uint32_t increment, uint32_t limit) {
  if (value >= limit || increment >= limit - value) return limit;
  return value + increment;
}

void pd1180_control_reset(pd1180_control_t *state) {
  *state = (pd1180_control_t){0};
}

void pd1180_control_disarm(pd1180_control_t *state) {
  pd1180_control_reset(state);
}

static bool safe_contract(const pd1180_inputs_t *in) {
  return in->pd_app_mode && in->epr_contract && in->contract_mv == REQUIRED_CONTRACT_MV &&
    in->contract_ma == REQUIRED_CONTRACT_MA && in->configuration_verified && in->sample_fresh &&
    in->motion_wiring_verified && !in->pd_fault && !in->efuse_fault &&
    in->watchdog_healthy && !in->stop_active && in->temperature_valid &&
    in->temperature_deci_c >= -400 && in->temperature_deci_c < 700;
}

bool pd1180_control_arm(pd1180_control_t *state, const pd1180_inputs_t *inputs) {
  if (!safe_contract(inputs) || inputs->temperature_deci_c > 550 || state->fault_latched) return false;
  state->armed = true;
  return true;
}

void pd1180_control_tick(pd1180_control_t *state, const pd1180_inputs_t *inputs, uint32_t elapsed_ms) {
  const bool contract_valid = safe_contract(inputs) && elapsed_ms > 0 && elapsed_ms <= 20u;

  if (!contract_valid || !state->armed) {
    if (state->armed) state->fault_latched = true;
    state->armed = false;
    state->contract_stable_ms = 0;
    state->motor_stable_ms = 0;
    state->power_start_ms = 0;
    state->power_permit = false;
    state->mcu_run = false;
    state->motor_commands_enabled = false;
    state->current_limit_permille = 0;
    return;
  }

  state->contract_stable_ms = saturating_add(state->contract_stable_ms, elapsed_ms, CONTRACT_STABLE_REQUIRED_MS);
  state->current_limit_permille = pd1180_thermal_limit_permille(inputs->temperature_deci_c);
  state->power_permit = state->contract_stable_ms >= CONTRACT_STABLE_REQUIRED_MS;
  if (state->power_permit && !state->mcu_run) {
    state->power_start_ms = saturating_add(state->power_start_ms, elapsed_ms, 1000u);
    if (state->power_start_ms >= 1000u) {
      pd1180_control_reset(state);
      state->fault_latched = true;
      return;
    }
  }

  const bool motor_valid = state->power_permit && inputs->motor_power_good && inputs->vmotor_in_range && inputs->driver_ready;
  if (!motor_valid) {
    if (state->mcu_run) {
      state->fault_latched = true;
      state->armed = false;
      state->power_permit = false;
    }
    state->motor_stable_ms = 0;
    state->mcu_run = false;
    state->motor_commands_enabled = false;
    return;
  }

  state->motor_stable_ms = saturating_add(state->motor_stable_ms, elapsed_ms, MOTOR_STABLE_REQUIRED_MS);
  state->mcu_run = state->motor_stable_ms >= MOTOR_STABLE_REQUIRED_MS;
  state->motor_commands_enabled = state->mcu_run;
}

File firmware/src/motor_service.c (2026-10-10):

#include "motor_service.h"

void pd1180_motor_service_reset(pd1180_motor_service_t *m) {
  pd1180_tmc_invalidate(&m->driver);
  m->status=(pd1180_tmc_status_t){0};
  m->attempted_configuration=false;
  m->applied_current_permille=0;
}
bool pd1180_motor_service(pd1180_motor_service_t *m, const pd1180_control_t *c,
                         pd1180_inputs_t *in, uint16_t requested) {
  in->driver_ready=false;
  if (!c->armed || !c->power_permit || !in->motor_power_good || !in->vmotor_in_range ||
      !in->configuration_verified || !in->motion_wiring_verified || !requested || requested>1000u) {
    pd1180_motor_service_reset(m);
    return false;
  }
  const uint16_t limit=(uint32_t)requested*c->current_limit_permille/1000u;
  if (limit<32u) return false;
  if (!m->driver.configured) {
    if (m->attempted_configuration) return false;
    m->attempted_configuration=true;
    if (!pd1180_tmc_configure_stepdir(&m->driver,limit)) return false;
    m->applied_current_permille=limit;
    if (!pd1180_tmc_set_chopper(&m->driver,true)) return false;
  }
  if (!pd1180_tmc_status(&m->driver,&m->status)) return false;
  // Verify the external step mode and its dcStep-disable pins continuously.
  if ((m->status.ioin&0x4Cu)!=0x40u) {
    pd1180_tmc_invalidate(&m->driver); return false;
  }
  if (limit!=m->applied_current_permille) {
    if (!pd1180_tmc_set_current(&m->driver,limit)) return false;
    m->applied_current_permille=limit;
  }
  in->driver_ready=true;
  return true;
}

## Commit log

2026-10-06 Create PD1180-EPR controller design
    [assembly-bom.csv, brake.kicad_sch, bridge_a.kicad_sch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]
2026-10-06 Release PD1180-EPR r0.3 prototype manufacturing package
    [alternatives.csv, bom-with-stock.csv, external-items.csv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]
2026-10-06 Add full product name to PCB silkscreen
    [pd1180-epr-r0.3-B_Cu.gbl, pd1180-epr-r0.3-B_Mask.gbs, pd1180-epr-r0.3-B_Silkscreen.gbo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]
2026-10-06 Add reusable PCB review and delivery gates
    [bom-with-stock.csv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]
2026-10-06 Fix cloud release packaging and expand documentation
    [bom-with-stock.csv]
2026-10-06 Add checked engineering review artifacts
    [bom-with-stock.csv]
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2026-10-06 Enforce zero-issue schematic style review
    [bom-with-stock.csv]
2026-10-06 Use standard USB-C model and clean schematic layout
    [bom-with-stock.csv]
2026-10-06 Fix cloud release and verify USB PD architecture
    [bom-with-stock.csv]
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2026-10-06 Show verified KiCad routing in cloud releases
    [bom-with-stock.csv]
2026-10-06 Correct C131334 connector model position
    [bom-with-stock.csv]
2026-10-07 Align mechanical reference and dual USB architecture
    [assembly-bom.csv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]
2026-10-07 Enforce live JLC stock and clean board markings
    [assembly-cpl.csv]
2026-10-07 Complete orderable PD1180-EPR board release
    [assembly-bom.csv, bom-with-stock.csv, brake.kicad_sch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]
2026-10-07 Fix schematic style and top-side reset switch
    [bom-with-stock.csv, brake.kicad_sch, bridge_a.kicad_sch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]
2026-10-07 Use one USB-C port for PD and data
    [bom-with-stock.csv, brake.kicad_sch, bridge_a.kicad_sch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]
2026-10-07 Sync single-port release evidence
    [bom-with-stock.csv]
2026-10-07 fix: finalize single-port EPR controller
    [alternatives.csv, assembly-bom.csv, bom-with-stock.csv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]
2026-10-07 fix: preserve imported transistor symbols
    [bom-with-stock.csv]
2026-10-08 fix: harden cloud build retry
    [bom-with-stock.csv]
2026-10-08 fix: widen USB-C schematic symbol
2026-10-08 fix: improve USB schematic pin spacing
2026-10-08 fix: restore imported FET symbols
2026-10-08 fix: restore imported power FET symbols
2026-10-08 fix: group serial decoupling capacitors
2026-10-08 fix: clean up USB-C protection schematic
2026-10-08 chore: update tscircuit to 0.0.2774
    [bom-with-stock.csv]
2026-10-08 fix: expose source and import files in circuit viewer
    [bom-with-stock.csv]
2026-10-08 fix: render imported components when switching preview files
    [bom-with-stock.csv]
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2026-10-08 fix: open verified routed PCB and repair local via path
2026-10-08 fix: build routed circuit output for hosted preview
2026-10-08 Build locked STM32 commissioning firmware and gate STEP/DIR ordering
    [bom-with-stock.csv]
2026-10-09 Implement dual USB power/data ECO and consolidate industrial I/O
    [assembly-bom.csv, bom-with-stock.csv, brake.kicad_sch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]
2026-10-09 Move industrial connector beside motor connector at board edge
    [bom-with-stock.csv, brake.kicad_sch, bridge_a.kicad_sch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]
2026-10-09 Move all components to top and reroute the four-layer PCB
    [bom-with-stock.csv, brake.kicad_sch, bridge_a.kicad_sch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]
2026-10-10 Complete top-side PCB routing and USB power-domain firmware for reference ECO (#1)
    * Add reference-board telemetry and revise motor-stage layout
    * Complete top-side routing and verify reference-board ECO
    [alternatives.csv, assembly-bom.csv, bom-with-stock.csv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]
2026-10-10 Finish USB return routing and TMC5160 commissioning support
    Reinforce the Q7-to-R115 motor-phase path, group the USB series resistors,
    and route USB trunks over stitched ground copper. Keep all 3,189 schematic
    records unchanged and all fitted components on top.
    Add pipelined SPI driver diagnostics, qualified low-current STEP/DIR
    service, fault latching and host coverage. The shipped firmware retains
    the hardware/TI-configuration motion lock.
    Fix cross-platform derived-length hashing and separate engineering review
    from the documented order hold. Regenerate routed manufacturing and 3D
    handoff artifacts; prevent reuse of a stale preview GLB.
    Validation: 31 engineering checks, 31 regression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
    [bom-with-stock.csv, kicad-front-positions.csv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]
2026-10-10 Enforce 0.30 mm via drills across PCB and exports
    [bom-with-stock.csv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]
2026-10-10 Correct driver supply and brake protection power limits
    Add the regulated 12 V TMC5160 gate supply and precision brake/OVP thresholds. Refresh top-side routing and manufacturing outputs with zero native DRC/ERC and complete connectivity. Verify native bypass paths and document calculations, sourcing, order holds, and unperformed powered tests.
    [alternatives.csv, assembly-bom.csv, bom-with-stock.csv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]
2026-10-10 Document assembled controller programming and operating requirements
    [bom-with-stock.csv]
2026-10-10 Set explicit driver protection and record pre-order audit
    [bom-with-stock.csv]
2026-10-10 Remove IMON bypass and prepare pre-shipment test handoff
    [assembly-bom.csv, bom-with-stock.csv, brake.kicad_sch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]
2026-10-10 Move USB power and data labels outside connector shells
    Place short PWR and DATA markings beside the USB receptacles so they remain
    visible after assembly. Keep source and native silkscreen synchronized and
    refresh the routed viewer, Gerbers and release evidence.
    Verified native board contents are identical except for the two text objects;
    all 3275 schematic records are unchanged. Required review passes 32 checks,
    with zero native DRC, unconnected, parity or ERC violations.
    [bom-with-stock.csv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]
2026-10-10 Preserve routed net names and enlarge USB knockout labels
    Update the KiCad importer and map each routed trace, via and filled polygon
    back to its actual source net. Reject missing, unknown or conflicting net
    identity, including branches without pad endpoints, and add regressions.
    Place PWR and DATA vertically in the requested edge spaces as 1 mm knockout
    silkscreen. Preserve all schematic records and every non-label native PCB
    object, and regenerate the checked viewer and manufacturing artifacts.
    Validation: 32 review checks and 42 regression tests; zero native DRC,
    unconnected, schematic-parity and ERC violations.
    [bom-with-stock.csv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]
2026-10-10 Fix motor mounting clearances and align bare QSH8618 assembly
    Move affected top-side components and repair their routed copper without changing the schematic or netlist. Add exact motor CAD, a proposed adapter and encoder stack, and exported-model axis and screw-clearance checks. Regenerate manufacturing and review artifacts. Full review passes; mechanical and powered qualification holds remain.
    [QSH8618-96.step, bom-with-stock.csv, brake.kicad_sch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]
2026-10-10 Use ordered STEPPERONLINE motor CAD and ratings
    [QSH8618-96.step, bom-with-stock.csv, external-items.csv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]
2026-10-10 Include motor assembly in default hosted 3D view
    [bom-with-stock.csv, motor-assembly-check.json]
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2026-10-11 Align PCB mounting holes with ordered motor CAD
    Move the four holes onto the 34HS31-6004S1 rear CAD axes and reroute nearby top-side components. Preserve schematic connectivity and add mounting geometry regressions. Native DRC, ERC, connectivity and schematic parity pass with zero issues; final release export is being refreshed separately.
2026-10-11 Refresh corrected motor assembly and manufacturing release
    Publish the aligned-hole Gerbers, routed viewer, assembly models, mounting documents and matching BOM/CPL with verified hashes. Preserve native copper coordinates while removing conversion noise so the hosted JSON stays within its existing size limit.
    Validation: 32 checks and 48 regression tests pass; native DRC, ERC, unconnected items and schematic parity are zero. Viewer consistency and all 49 delivery files and six archives pass. Physical qualification and the documented order hold remain unchanged.
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2026-10-11 Update tscircuit toolchain and refresh verified release
    Upgrade tscircuit to 0.0.2821 and circuit-to-svg to 0.0.445. Retain the verified core compiler through an explicit compatibility pin so fixed schematic sheet frames remain unchanged. Point the library main at its compiled output while retaining the TSX source entrypoint.
    Validated with 32 review checks, 50 regression tests, all delivery hashes and six archives. A clean hosted CI build completed in 136 seconds with identical routed circuit output and motor preview.
2026-10-11 Make centered encoder optional and specify the JST motor harness
    Place U18 and its local capacitors on bottom as DNP, exclude them from
    fitted BOM/CPL and paste, and reroute their connections. Keep all fitted
    parts on top and preserve the motor, power, USB and mounting geometry.
    Document NEMA17/NEMA23 references, the VH mating cable and connector
    purposes. Refresh native checks and manufacturing/review artifacts.
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2026-10-11 Add routed diagnostics and isolated PD programming access
    Add RGB and independent power indication, a reset-safe driven buzzer,
    isolated EEPROM programming access, and eight power/programming probes.
    Preserve top-side assembly and local bypass paths, and exclude all bare
    service contacts from stencil paste.
    Refresh firmware, Gerbers, BOM/CPL, 3D models and review documentation.
    The full review passes 32 checks and 55 regression tests, with zero native
    DRC, ERC, unconnected and schematic-parity issues. TI configuration and
    physical qualification remain explicit order holds.
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2026-10-11 Fix source warnings and organize schematic on A4 sheets
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2026-10-11 Correct float32 bounds in mechanical CAD exports
2026-10-11 Fix assembly export reproducibility and add programming readback checks
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2026-10-12 Document assembly identity and missing endpoint findings
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2026-10-12 Replace J7 with onboard control and simplify motor assembly
    Add local START/STOP and fail-closed motion firmware, remove unsupported external command circuitry and mounting hardware, and preserve the four PCB holes and braking protection.
    Refresh native PCB routing, manufacturing files, assembly previews, and build evidence. Local source/site builds and 66 regression tests pass; sourcing, placement review, and hardware qualification remain open.
2026-10-13 Add power and brake protection ECO for the ordered NEMA34 motor
    Use TPS26630 1x latch-off current limiting at 4.27 A nominal and lower the
    motor inhibit threshold to 53.18 V. Add a 100 V brake-cable clamp and ADC
    startup continuity feedback, with a 3.8 A RMS motor-current ceiling and
    locked 0.827 A / 10 rpm unloaded commissioning profile.
    Update the native PCB, 24-sheet schematic, firmware, calculations, nine
    behavioral simulation cases and engineering delivery artifacts. Preserve
    unrelated component geometry and all four mounting holes.
    Native DRC/ERC/parity, connectivity, critical copper, power routing,
    firmware tests and STM32 image checks pass. Full verification retains
    three failing g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
2026-10-13 Refine protection limits and restore native component references
    Restore footprint-native reference labels, including SW1/SW2, and retain
    source, assembly and external-equipment review updates.
    Apply TPS26630 with R25 4.99k, R61 16.2k and R66 1.2k to source and native
    CAD. Retain the restricted current ceiling and motion/configuration locks.
    Record threshold tolerances, thirteen behavioral simulation cases, source
    hashes and native geometry-equivalence evidence.
    Validation: source/assembly builds, typecheck, 27 design tests, 14 power
    checks and firmware host tests pass. Native ERC and unconnected/parity
    counts are zero. Full review fails the stock gate; 403 silkscreen/text
    findings, brake-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
2026-10-13 Restore native component names in the default PCB and 3D viewer
    Remove hidden-reference overrides and detached captions, including stale
    U20 and the SW1 caption beside R133. Restore native {NAME} templates in
    custom footprints and check all 255 references, including SW1/SW2, in
    compiled source, native KiCad and the actual release/circuit.json viewer.
    Keep default rotations, sizes and overlaps as explicitly requested.
    Native non-reference data and all compiled electrical, schematic and
    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
2026-10-13 Fix brake-monitor timing and Linux harness checks; reconcile sourcing (#5)
    * Review sourcing replacements and document programming and hardware acceptance
    * Monitor runtime brake continuity and complete prototype review handoff
2026-10-14 Use manufacturer splice CAD and exact stock evidence (#6)
    * Replace provisional TE320559 splice cylinders with manufacturer CAD
    * Finalize exact stock checks and manufacturer-CAD review delivery
    * Record index failures separately from official stock authority
2026-10-14 Use native U16 and U35 footprints with supplier CAD (#8)
    * Use native U16 footprint with explicit LQFP CAD
    * Use native U35 footprint and retain TSSOP CAD
2026-10-14 Replace unavailable MCU and expander with stocked JLC parts
    Use STM32G0B1CEU6 with a grounded UFQFPN48 exposed pad and a 512 KiB
    firmware/readback target. Use PCA9538PWR with a PD-powered reset buffer,
    bypass capacitor and pulldown to address independent-rail reset injection.
    Regenerate local routing, native/manufacturing artifacts, assembly data,
    stock evidence and the routed viewer. Preserve unrelated copper and holes
    with the existing protected projection. Retain motion locks and physical
    qualification holds. Preserve quoted DSN net names and native EP paste sizing.
2026-10-14 Move USB power and data ports to the PCB edge
    Move J1 and J10 2 mm outward with attached local routing, preserve unrelated geometry, and regenerate manufacturing and release artifacts. Add native mating-face and placement regressions with drawin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
    Validation: 43 verification checks, 104 regression tests, 14 power simulations, native electrical/connectivity/parity/ERC checks and 89 delivery files pass. Physical cable and hardware qualification 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
2026-10-15 Add J3 brake assembly and keep only the encoder on the bottom
    Add the mating housing, contacts, 16 AWG leads, ring terminals and manufacturer resistor CAD, with explicitly provisional cooling and guard geometry. Document the harness and qualification boundaries.
    Move C52/C53 to the top while retaining the optional DNP encoder. Verify the short through-via bypass, preserve unrelated copper and mounting holes, and regenerate native manufacturing and release evidence.
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2026-10-20 Fix copper necks and consolidate power pours (#11)
2026-10-27 Enforce source trace width and GND pour rules in native PCB (#13)
2026-10-28 Add a parallel VMOTOR feed with native copper validation (#15)
    Add seven 1.5 mm bottom-layer segments from C22 to the Q6 drain vias while preserving all original native objects. Include replay guards, 18-path DC comparisons, fresh native DRC and synchronized rev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
2026-10-29 Reproduce U1 CC alias merging in the NEMA34 source and viewer (#16)
    * test: reproduce merged U1 connector and protected CC nets
    * test: keep the CC repro outside selectable TSX board sources
2026-10-29 fix: separate U1 connector CC aliases and regenerate circuit JSON (#17)
2026-10-29 chore: update tscircuit and synchronize board validation (#20)
    * chore: evaluate tscircuit 0.0.3039 upgrade
    * fix: move R3 courtyard inside curved board boundary
    * fix: synchronize R3 placement and restore upgrade checks
2026-11-02 Replace STM32/TMC5160 with RP2040 and DRV8462 at 48 V EPR (#21)
    * feat: draft RP2040 and DRV8462 48V controller redesign
    Replace the MCU, motor bridges and optional encoder; add motion-locked RP2040 commissioning firmware and new architecture checks. Retain TPS26750 EPR and independent protection/braking. Record fresh unrouted KiCad results and fail the release gate on historical native evidence. Routing, thermal, sourcing and physical qualification remain open.
    * Show current draft preview and preserve native routing review evidence
    * Complete RP2040 native routing and verified review artifacts
    * Check current CC vias in both local review and CI
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2026-11-02 Fix current manufacturing handoff and guard stale release instructions (#23)
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2026-11-05 Fix startup readiness and complete commissioning handoff (#27)
    * Fix startup readiness and add bounded commissioning profiles
    * Refresh current assembly and order-preparation guidance
2026-11-07 Fix MOTOR_A2 connection lost during KiCad export refill (#29)
    * Bridge MOTOR_A2 pour neck for KiCad export connectivity
    * Refresh native evidence for MOTOR_A2 bridge
    Regenerate the manufacturing export, DRC/ERC, Kelvin, USB, bypass,
    filled-copper, power-simulation and release evidence against the bridged
    board, and review the routing fingerprint for the new power-feed inputs.
    Stale evidence was failing the review. Fabrication gates remain held.
    * Replace R65 C723637 with stocked C328424
    C723637 has zero official JLCPCB Available Order Qty. Use RESI
    PTFR0603B20K0P9 (20k 0.1% 25 ppm/C thin film, 100 V, 0603) with no
    footprint or copp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
2026-11-07 Use the Raspberry Pi recommended crystal circuit (#31)
    * Add first-article checklist for post-assembly work
    List what is checked without a board and what needs an assembled one: U3
    EEPROM programming, crystal startup and USB, and motor current. Record the
    steps, pass criteria and pre-order decisions in one place, with links to the
    detailed procedures.
    Note that Y1 differs from the crystal Raspberry Pi recommends. Refresh the
    verification record and generated reports; board and source are unchanged.
    * Use the Raspberry Pi recommended crystal circuit
    Replace Y1 X322512MSB4SI (80 ohm ESR, CL 20 pF) with ABM8-272-T3 (50 ohm ESR,
    CL 10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
